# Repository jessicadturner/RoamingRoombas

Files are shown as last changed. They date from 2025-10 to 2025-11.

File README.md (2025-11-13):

# Roaming Roombas: DIY Social Robot Platform

Roaming Roombas is a versatile, low-cost platform for building expressive and customizable social robots using the Create3 Roomba as a movement hub. Designed for Human-Robot Interaction (HRI) research and education, it enables rapid prototyping through 3D printing or cardboard crafting, and supports real-time facial expressions and behavior control via Python or ROS2.

## 🚀 Features

- **Modular Design**: Easily adapt robot size and appearance using 3D printed or cardboard components.
- **Expressive Faces**: Display reactive facial expressions on a touchscreen or mobile device.
- **Flexible Behaviors**: Define robot actions using a storyboard-driven software architecture.
- **Open Source**: Hardware designs and software are customizable and extensible.
- **Low-Cost**: Build robots for under \$600 USD using accessible materials and components.

## 🧱 Architecture

### Hardware

- **Movement Hub**: iRobot Create3
- **Controller**: Raspberry Pi 4B
- **Face Display**: 7" touchscreen or mobile device
- **Sensors**: IR proximity and bump sensors
- **Power**: Powered via Create3’s onboard battery

A full price list with links to necessary components is available in the Hardware folder above.

### Software

- **Languages**: Python or ROS2
- **Components**:
  - `MotionNode`: Manages movement phases and sensor input
  - `PhaseController`: Links behaviors to expressions
  - `BlinkManager`: Adds lifelike blinking
  - `Storyboard`: Maps user-defined scenarios to robot actions

## Setup of Create3 Platform with Raspberry Pi

### Prerequisites

1. **Install Ubuntu on your Raspberry Pi**  
   Follow the official installation instructions: [Ubuntu for Raspberry Pi](https://ubuntu.com/download/raspberry-pi)

   > **Recommended**: Ubuntu 22.04 LTS (Jammy) for ROS 2 Humble compatibility

2. **Install ROS 2 on the Raspberry Pi**  
   Follow the binary installation guide: [ROS 2 Humble Binary Installation](https://docs.ros.org/en/humble/Installation/Ubuntu-Install-Debians.html)

   > **Important**: Install the full desktop version (`ros-humble-desktop`) or at minimum the base version (`ros-humble-ros-base`)

### Connecting Raspberry Pi and Create3 via USB-C

1. **Physical Connection**  
   Connect your Raspberry Pi to the Create3's USB-C port using a USB-C cable.

2. **Follow Setup Guide**  
   Follow [Jim Bennett's guide](https://jimbobbennett.dev/blogs/irobot-create3-connect-a-pi/) for detailed instructions on configuring USB-C communication between your Raspberry Pi and the Create3.

### Configure ROS 2 Domain ID

The ROS 2 Domain ID must match between your Raspberry Pi and Create3 for them to communicate.

#### On the Raspberry Pi:

1. Open your `.bashrc` file:
  
    ```bash
       nano ~/.bashrc
    ```

2. Add the following line (use domain ID 0 unless you have a specific reason to use another):
    
    ```bash
       export ROS_DOMAIN_ID=0
    ```

3. Save the file (`Ctrl+O`, `Enter`, `Ctrl+X`) and apply the changes:

    ```bash
       source ~/.bashrc
    ```

#### On the Create3:

1. **Find the Create3's IP address**:
   
   **If connected via USB-C**, the Create3 has a fixed IP address:
    ```
       192.168.186.2
    ```
   **If connected via WiFi**, find the IP address by:
   - Checking your router's DHCP client list for a device named `iRobot-XXXX` (where XXXX is part of the serial number)
   - Pinging the robot by hostname: `ping iRobot-XXXX.local` (replace XXXX with your robot's identifier)
   - Using the Bluetooth `create3_ip_address.py` example from [python.irobot.com](https://python.irobot.com)

2. **Access the Create3 Web Interface**:
   - Open a web browser and navigate to: `http://<CREATE3_IP_ADDRESS>`
   - For USB connections: `http://192.168.186.2`
   - For WiFi: Use the IP address found in step 1

3. **Configure the Domain ID**:
   - Navigate to the **Application** → **Configuration** section
   - Set the **ROS 2 Domain ID** to match your Pi (e.g., `0`)
   - Optionally set the **ROS 2 Namespace** if needed (default is usually fine)
   - Click **Save** and then **Restart Application**

### Verifying the Connection

After configuration, verify that your Raspberry Pi can see the Create3's ROS 2 topics:

1. **On the Raspberry Pi**, open a terminal and run:

```bash
   ros2 topic list
```

2. You should see Create3-related topics such as:

```
   /battery_state
   /cmd_audio
   /cmd_lightring
   /cmd_vel
   /dock
```

(among others)

> **Troubleshooting**: If you don't see any topics:
>
> - Verify both devices are on the same network (if using WiFi) or properly connected via USB-C
> - Double-check that the ROS_DOMAIN_ID matches on both devices
> - Restart both the Raspberry Pi and Create3
> - Ensure your ROS 2 installation is sourced: `source /opt/ros/humble/setup.bash`

## Setting up ROS2

### ROS2 Workspace

To set up the ROS2 workspace, you have two options:

1. **Official Documentation**: Follow the [Creating a Workspace - ROS2 Documentation](https://docs.ros.org/en/kilted/Tutorials/Beginner-Client-Libraries/Creating-A-Workspace/Creating-A-Workspace.html)

2. **Video Tutorial** (Recommended): Watch ["ROS2 Tutorial – ROS2 Humble Crash Course"](https://www.youtube.com/watch?v=Gg25GfA456o) by Robotics Back-End, from **21:29 to 29:18**, which provides a clear walkthrough of setting up a ROS2 workspace.

### Creating Your Robot Controller Package

After setting up your workspace, create a Python package named `my_robot_controller`:

```bash
cd ~/ros2_ws/src
ros2 pkg create my_robot_controller --build-type ament_python
```

You should end up with a `ros2_ws` directory that has the following structure:

```
ros2_ws/
└── src/
    └── my_robot_controller/
        ├── my_robot_controller/
        │   └── __init__.py
        ├── resource/
        │   └── my_robot_controller
        ├── test/
        ├── package.xml
        ├── setup.cfg
        └── setup.py
```

## Running Example Code

To run the programs provided in the software directory of this repository:

1. **Copy the Python file** (e.g., `creepy_robot.py`) into the **inner** `my_robot_controller` directory (the one containing `__init__.py`).

   ```
   src/
   ├── my_robot_controller/
   │   ├── my_robot_controller/
   │   │   ├── __init__.py
   │   │   ├── creepy_robot.py
   │   ├── resource/
   │   ├── test/
   │   ├── package.xml
   │   ├── setup.cfg
   │   └── setup.py
   ```

2. **Update your package configuration** by ensuring the correct dependencies for the example code are in your `package.xml`:

   ```xml
   <?xml version="1.0"?>
   <package format="3">

   <!-- existing content  -->

   <depend>rclpy</depend>
   <depend>geometry_msgs</depend>
   <depend>irobot_create_msgs</depend>
   <exec_depend>python3-pygame</exec_depend>

   <!-- existing content  -->

   <export>
      <build_type>ament_python</build_type>
   </export>
   </package>
   ```

3. **Add the entry point** in your `setup.py`:

   ```python
   # ... existing imports and content ...

   setup(
      # ... existing parameters ...
      entry_points={
         'console_scripts': [
               'creepy_robot = my_robot_controller.creepy_robot:main',
         ],
      },
   )

   ```

### Building the Program

1. Navigate to the **top level** of your `ros2_ws` directory:

   ```bash
   cd ~/ros2_ws  # Adjust path if your workspace is located elsewhere
   ```

2. Build your workspace:

   ```bash
   colcon build --symlink-install
   ```

   > **Note**: The `--symlink-install` flag allows you to modify Python scripts without rebuilding.

3. **Source your workspace**:
   ```bash
   source install/setup.bash
   ```

### Running the Program

Now you can run your program:

```bash
ros2 run my_robot_controller creepy_robot
```

> **Troubleshooting**: If you get a "package not found" error, make sure you've sourced the workspace in your current terminal (`source install/setup.bash`).

## 🤖 Example Robots

### Bubbles

Bubbles
Bubbles is a cute, child-friendly robot with smooth movements and rounded features. Ideal for school and playful environments.

### Spike

Spike
Spike is angular and intimidating, designed for security and patrol tasks, featuring jerky movements and grumpy expressions.

### BeachBot

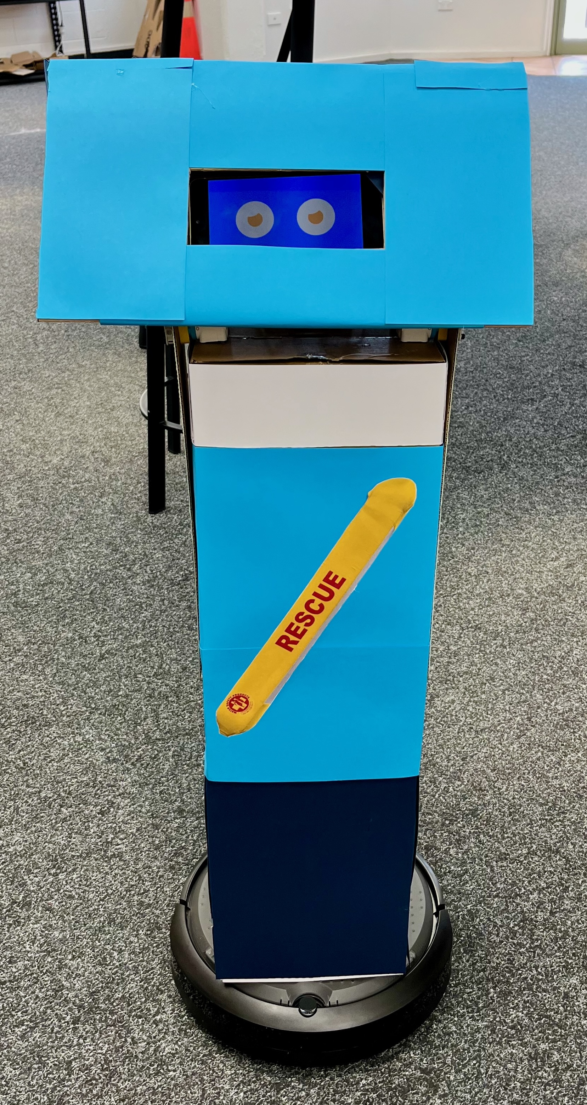
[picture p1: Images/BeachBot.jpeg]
BeachBot

BeachBot is crafted from cardboard and Lego, designed to assist beachgoers with safety info and navigation.

## 🙏 Acknowledgements

We gratefully acknowledge the contributions of students and participants involved in the co-design workshops that shaped the development of the Roaming Roombas platform. Their creativity, diverse use case ideas, and design insights were instrumental in validating the feasibility and adaptability of the system.

**With special thanks to** the developers of **Bubbles**, **Spike**, and **BeachBot** for their innovative prototypes and commitment to accessible social robots. This project would not have been possible without their enthusiasm and imagination.

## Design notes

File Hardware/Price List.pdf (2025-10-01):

Item | Item Cost Number | | Total | Source | Cardboard $ 479.93
Raspberry Pi 4B | $ 75.00 | 1 | $ 75.00 | https://www.canakit.com/raspberry-pi-4-8gb.html
Raspberry Pi Touch Display | $ 65.95 | 1 | $ 65.95 | https://www.canakit.com/raspberry-pi-lcd-display-touchscreen.html
USB-C Cable | $ 8.00 | 2 | $ 16.00 | https://www.amazon.com/Amazon-Basics-Charger-480Mbps-Certified/dp/B01GGKZ4NU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
Create3 Robot | $ 300.00 | 1 | $ 300.00

https://media.irobot.com/2022-04-05-In-Celebration-of-National-Robotics-Week,-iRobot-
Launches-the-Create-R-3-Educational-Robot (https://media.irobot.com/2022-04-05-In-Celebration-of-National-Robotics-Week,-iRobot-Launches-the-Create-R-3-Educational-Robot) | 3D Printed $ 571.89

pe9V9Yhr3P14bkDVrXM0ltZ_6DTeBIYo76yCMbCOY_Yj1fXQnPfbRBRAo17_yMSkwYyVEGKRDOrDaB 6le_sR_PFx52ulOsN9sT-4X4cNh5-Qx4vrj6RqGEW553xgsKL2ga3mBtWgge9u_DzGQ9xbNlyzbgaQgwzoT6ckIXSvvL4zJgsJ_IieTDMGE6lz_tnlT7qumlaiQlGiVFRWGcPWq73BYMdwJIqJxLQ.a2aCq4aJwM6vYoPtZICIYP4Qwd-H7sslbmge8YYv3aI&dib_tag=se&keywords=usb-c%2Bcable&qid=1758520567&sprefix=usb-c%2Bcabl%2Caps%2C329&sr=8-1-spons&sp_csd=d2lkZ2V0TmFtZT1zcF9hdGY&th=1 (https://www.amazon.com/Amazon-Basics-Charger-480Mbps-Certified/dp/B01GGKZ4NU?sp_csd=d2lkZ2V0TmFtZT1zcF9hdGY)

Screw pack + heat sinks | $ 22.98 | 1 | $ 22.98

https://www.amazon.com/Zxglxinyao-Assortment-Stainless-Phillips-ScrewsSet/dp/B0CGRGLRXQ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 BO5021pAnSA%3D%3D&sprefix=screw+pack+and+heat+sinks+m3%2Caps%2C244&sr=1-2-6024b2a3-78e4-4fed-8fed-e1613be3bccespons&sp_csd=d2lkZ2V0TmFtZT1zcF9zZWFyY2hfdGhlbWF0aWM&psc=1 (https://www.amazon.com/Zxglxinyao-Assortment-Stainless-Phillips-ScrewsSet/dp/B0CGRGLRXQ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) https://www.amazon.com/HANGLIFE-Heat-Set-Threaded-Printing-Components/dp/B0CS6VZYL8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 yY9nziEYxkt4vhQcqM6ldH2cqMQFMR-Ww5MxClRg&dib_tag=se&keywords=heat%2Bsinks%2Bm3&qid=1758520700&sprefi x=heat%2Bsinks%2Bm3%2Caps%2C288&sr=8-1-spons&sp_csd=d2lkZ2V0TmFtZT1zcF9hdGY&th=1 (https://www.amazon.com/HANGLIFE-Heat-Set-Threaded-Printing-Components/dp/B0CS6VZYL8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)

Filament | $ 22.99 | 4 | $ 91.96

https://www.amazon.com/Creality-PLA-1-75mm-Hyper-Dimensional/dp/B0C2BL9T5V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 TGlaPfUnS3Dz7Tx5Pgp5-kbgZLa-Ti428P_FH8_jHqeLBxd1J7HdUAT_YtZfiLTbY6HdPs1HdO6kRrb4RlYY59VKNWKPb4b9e_NNddh6W5L wYUQVVJuk1-upPU1JUGVxVgQ2MPiijtyKlHmW86ipvPueMDsDaCGpiGalvhHEnl4qlWgGMBlf3Sg5IjBLvXGYKbawCTwlt0Op0pe62VBEAEY WEwUCpz4R6s.Knsv3AvVqcfPpTREL08fu36pKkC8uly1QJd2EGSp5U&dib_tag=se&keywords=creality%2Bfilament&qid= 1758520747&sprefix=creality%2Bfilamen%2Caps%2C310&sr=8-1-spons&sp_csd=d2lkZ2V0TmFtZT1zcF9hdGY&th=1 (https://www.amazon.com/Creality-PLA-1-75mm-Hyper-Dimensional/dp/B0C2BL9T5V?sp_csd=d2lkZ2V0TmFtZT1zcF9hdGY)

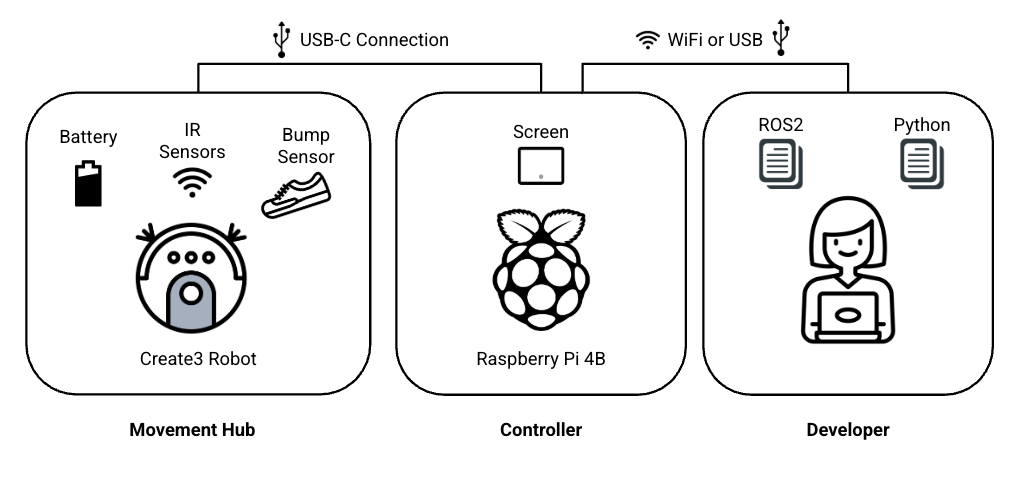
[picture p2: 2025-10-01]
Hardware/Hardware.png

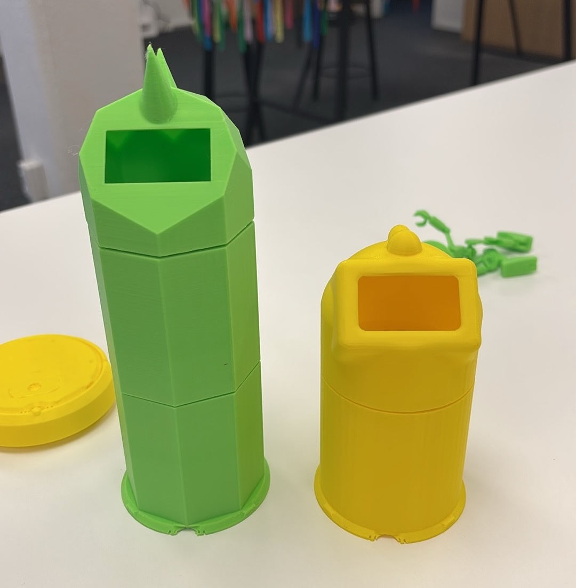
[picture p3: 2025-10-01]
Images/forms.jpeg

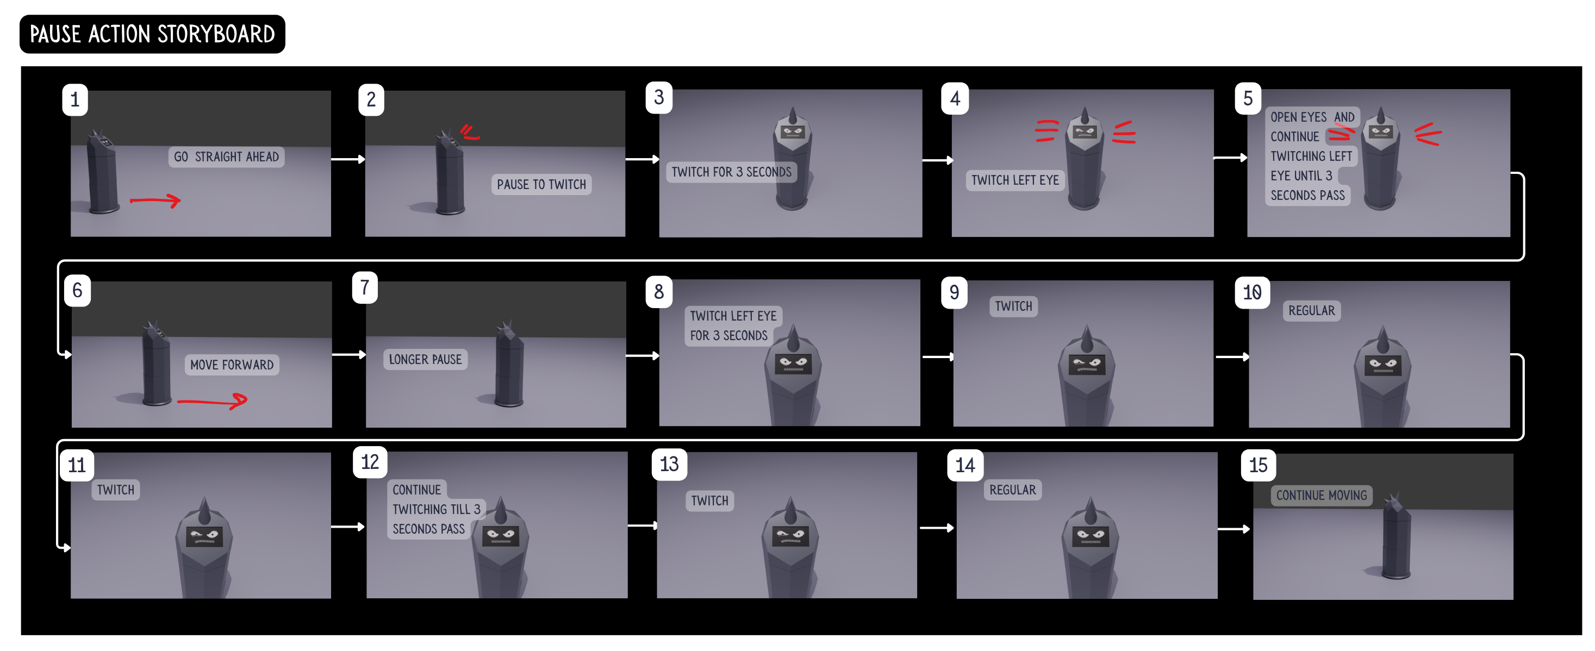
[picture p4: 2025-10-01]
Images/Storyboards/Creepy Behaviour Storyboarding Pause.png

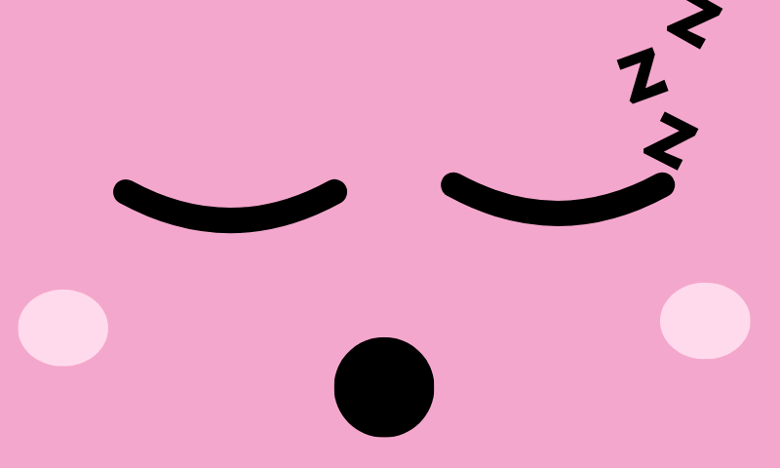
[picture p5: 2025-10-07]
Images/Expressions/Cute Expressions/Sleepy.png

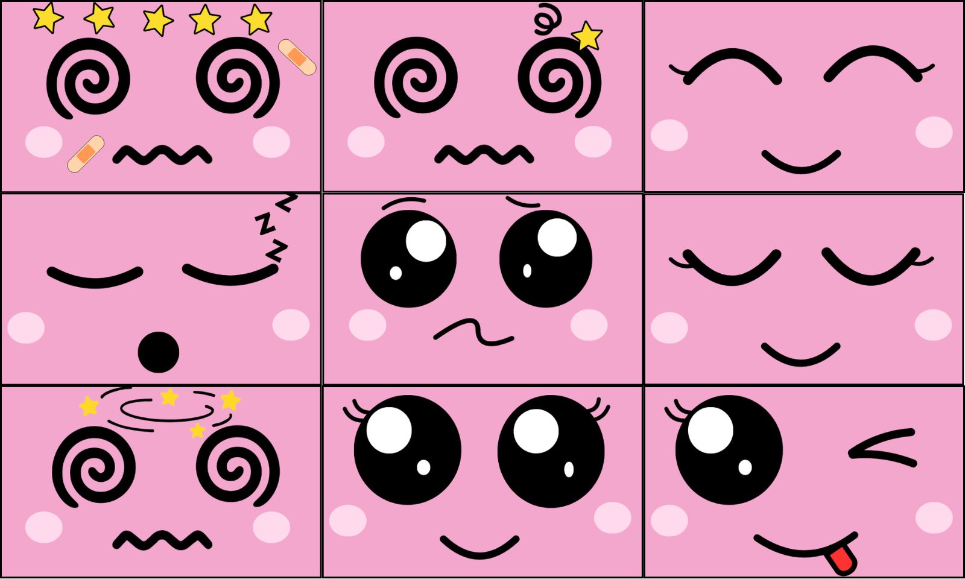
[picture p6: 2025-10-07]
Images/Expressions/Cute Expressions/CuteFullExpressionSet.jpg

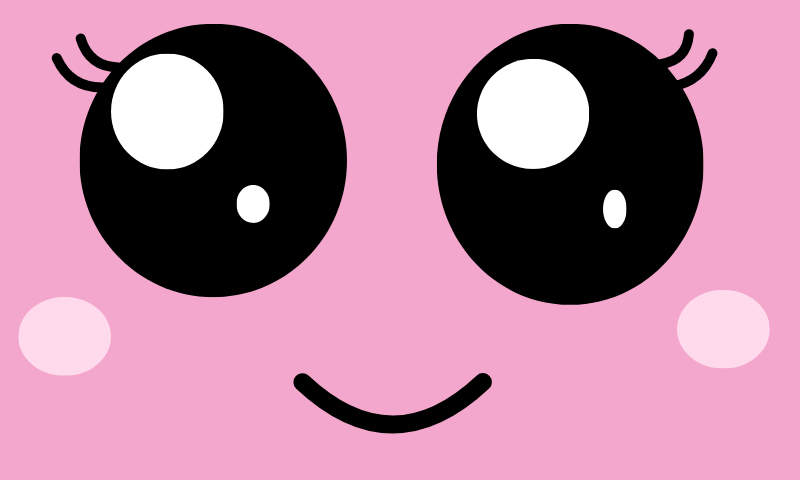
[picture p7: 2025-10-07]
Images/Expressions/Cute Expressions/Normal.png

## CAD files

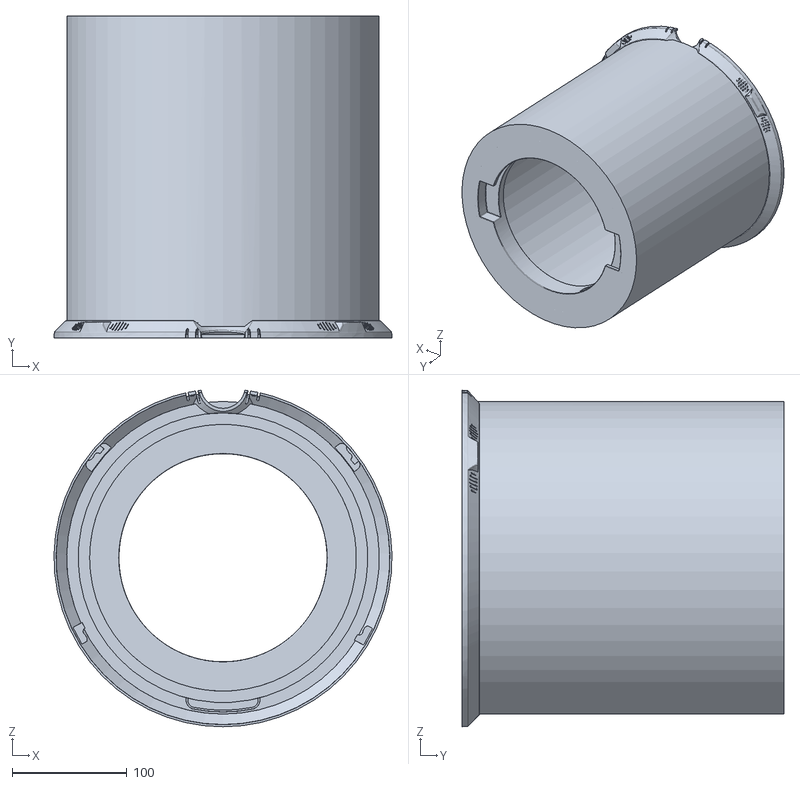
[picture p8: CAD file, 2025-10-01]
3D Models/STL Cute Base Final.STL
294.1 x 280.0 x 292.9

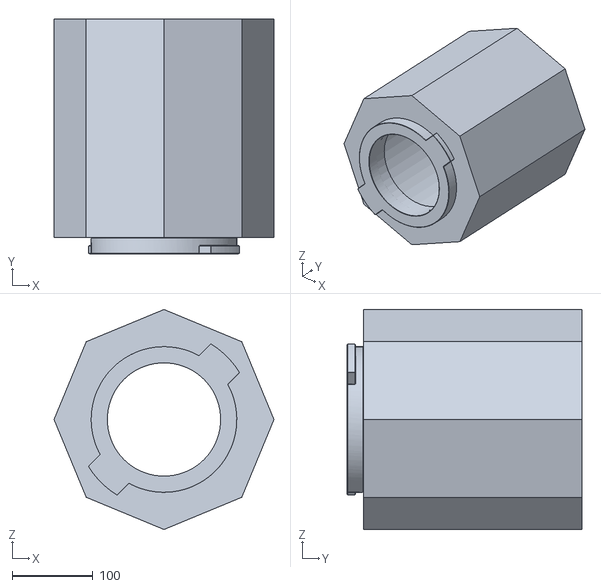
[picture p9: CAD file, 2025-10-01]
3D Models/Creepy Body Final.STL
272.0 x 290.0 x 272.0

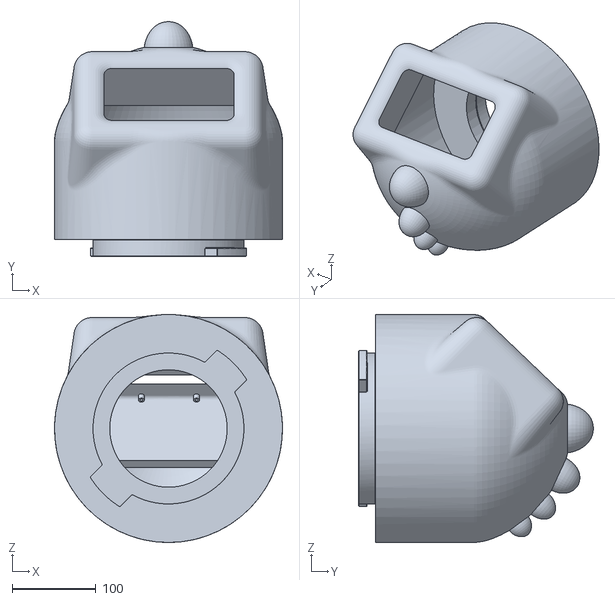
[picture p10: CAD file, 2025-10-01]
3D Models/STL Cute Head Final.STL
272.0 x 280.0 x 272.0

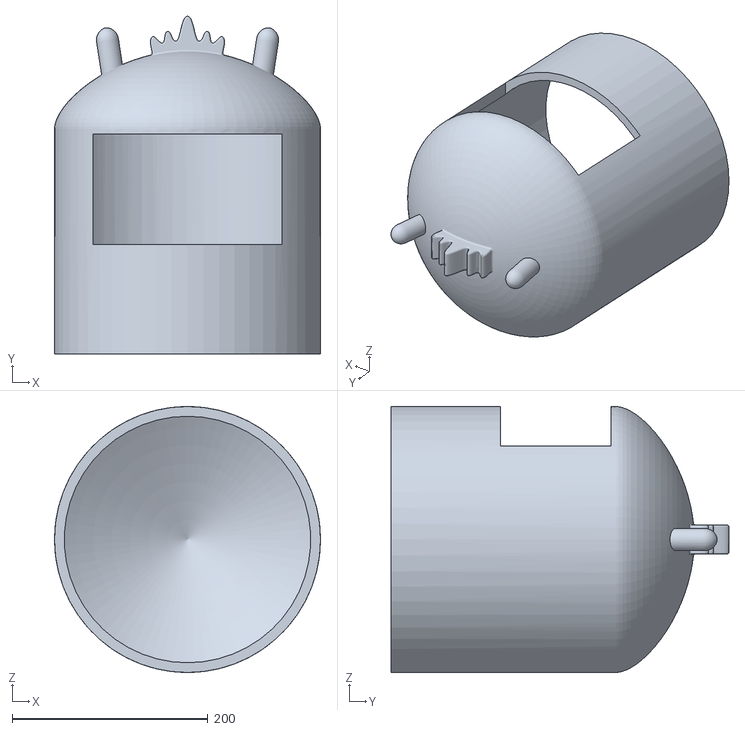
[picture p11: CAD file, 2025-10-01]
3D Models/Cute Design Changed 4 Print.STL
272.0 x 345.3 x 272.0

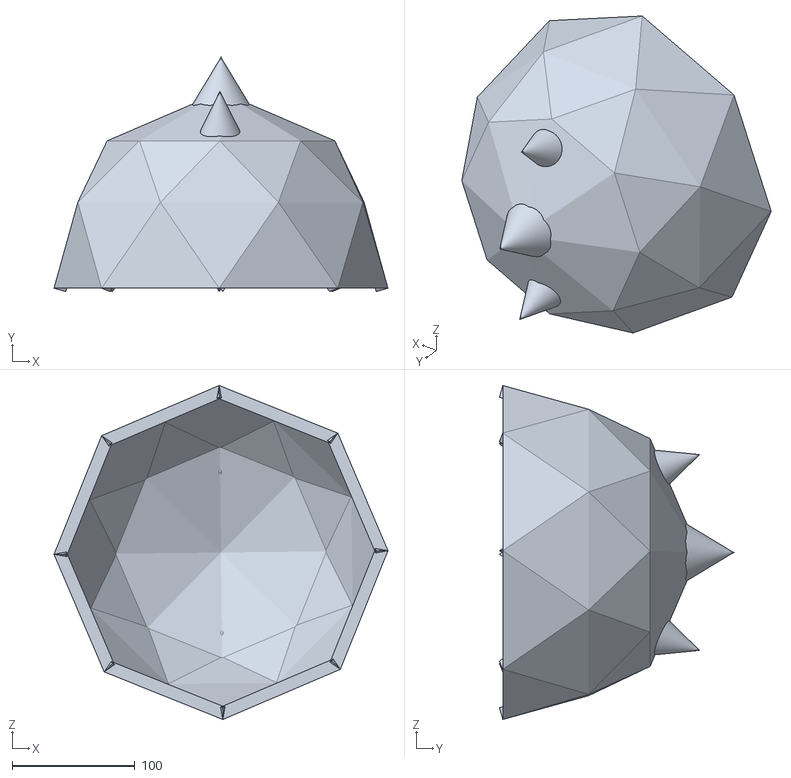
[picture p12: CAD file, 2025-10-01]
3D Models/Creepy Design Changed 2 Print - Creepy Design 2 Dome-2.STL
272.0 x 190.7 x 272.0

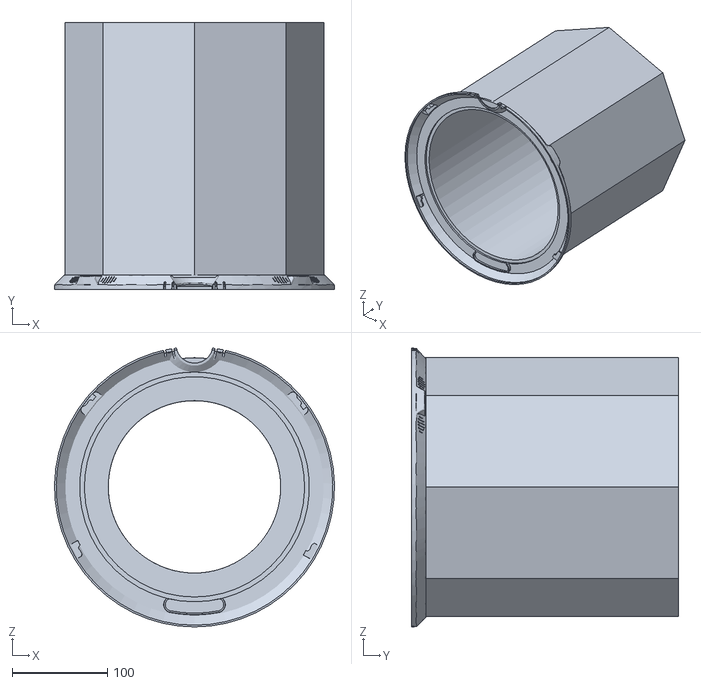
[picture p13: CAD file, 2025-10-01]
3D Models/Creepy Base Final.STL
294.1 x 280.0 x 292.9

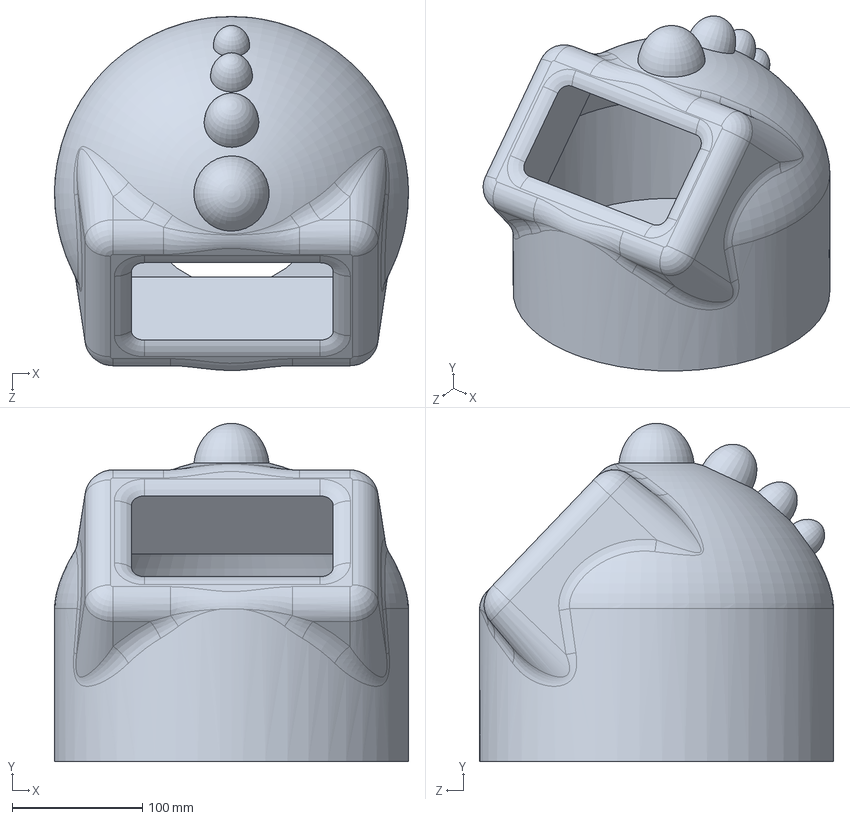
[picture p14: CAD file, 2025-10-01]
3D Models/Final PT2 Cute Head (No Lock).SLDPRT
272.0 x 260.0 x 272.0 mm

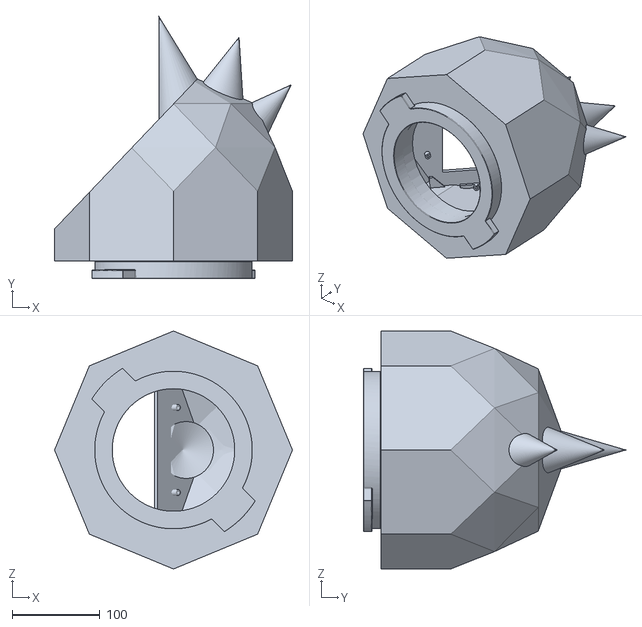
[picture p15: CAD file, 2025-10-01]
3D Models/Creepy Head Final.STL
272.0 x 300.0 x 272.0

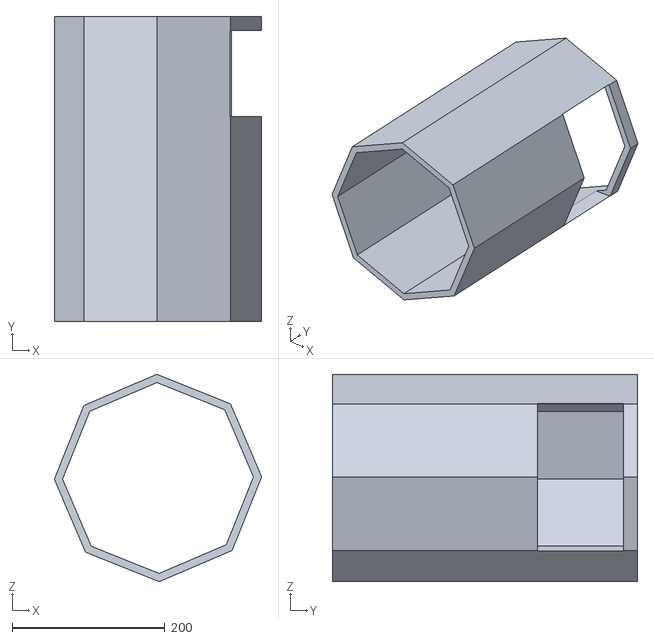
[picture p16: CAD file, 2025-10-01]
3D Models/Creepy Design Changed 2 Print - Creepy Design Changed 2-1.STL
272.0 x 400.0 x 272.0

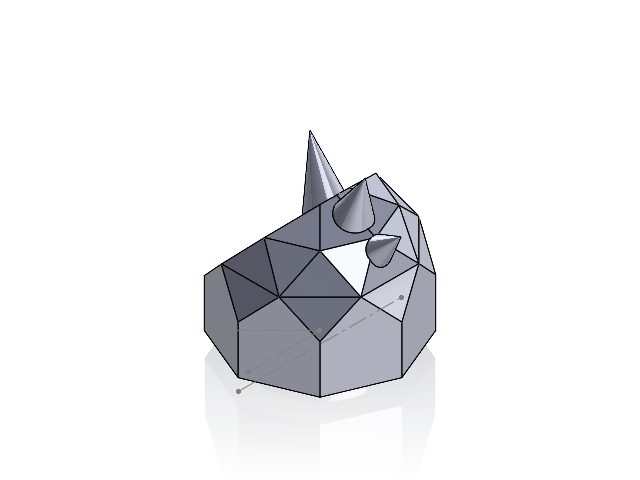
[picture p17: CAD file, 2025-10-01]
3D Models/New PT3 Creepy Dome (with lock) Shaheer.SLDASM
New PT3 Creepy Dome (no lock) Shaheer
supper sized 2 teeth part

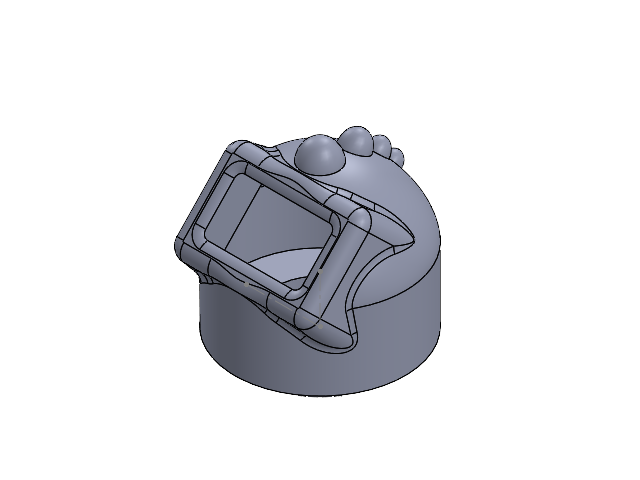
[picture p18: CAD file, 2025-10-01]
3D Models/Cute Head Final.SLDASM
Cute head new
supper sized 2 teeth part

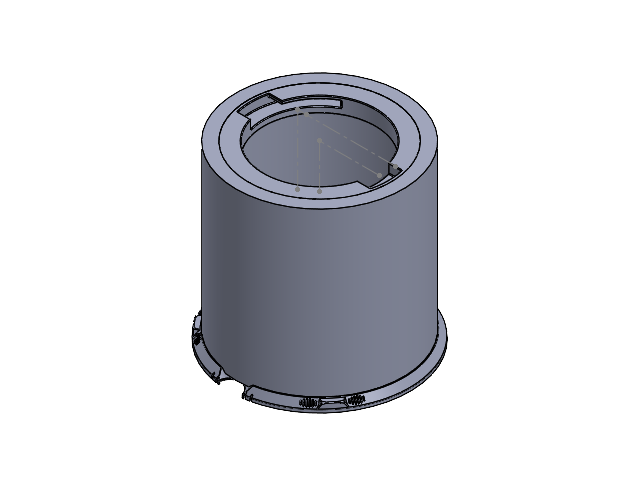
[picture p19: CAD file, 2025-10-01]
3D Models/Cute Base Final.SLDASM
Shaheer Cute Body (with lock) PT1
supper sized locking part

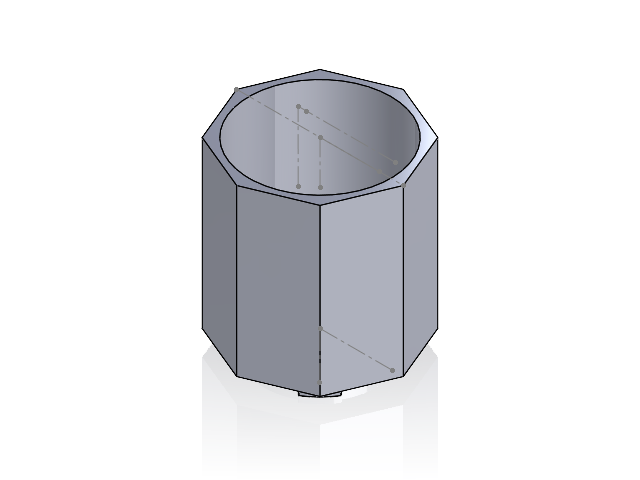
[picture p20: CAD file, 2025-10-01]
3D Models/New PT2 Creepy Body (with lock) Shaheer.SLDASM
New PT2 Creepy Body (no lock) Shaheer
supper sized 2 teeth part
supper sized locking part

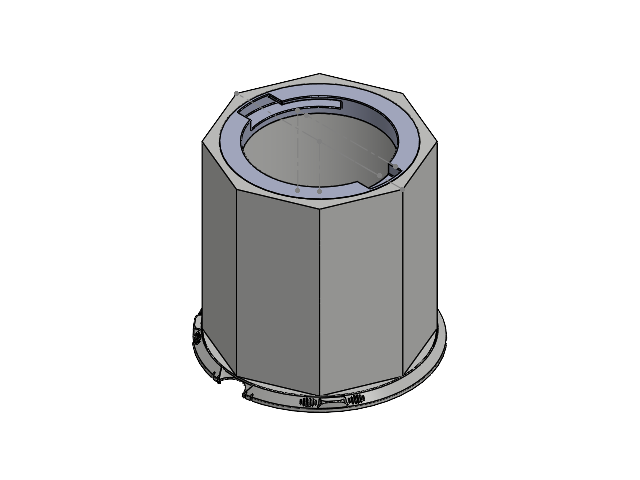
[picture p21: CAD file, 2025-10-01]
3D Models/New PT1 Creepy Base (with lock) Shaheer.SLDASM
New PT1 Creepy Base (no lock) Shaheer
supper sized locking part

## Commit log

2025-10-01 Added 3D Models
    [Creepy Base Final.STL, Creepy Body Final.STL, Creepy Design Changed 2 Print - Creepy Design 2 Dome-2.STL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]
2025-11-12 Update README.md
    Added set up instructions for create3 and raspberry Pi
